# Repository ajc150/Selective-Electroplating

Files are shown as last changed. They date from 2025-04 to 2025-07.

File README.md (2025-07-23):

# Selective-Electroplating
Welcome to the Selective Electroplating GitHub!

This repository serves as a comprehensive introduction to CNC-based selective electroplating. Whether you're a student, researcher, or hobbyist, this guide provides everything you need to get started—from foundational electrochemical concepts to a full walkthrough of materials, setup, calibration, and image plating.

Here, you'll find:
* Step-by-step instructions for building and operating a selective electroplating system
* Supplementary code, G-code scripts, and CAD files for hardware fabrication
* Practical guidance on electrolyte preparation, process tuning, and image-based deposition

Use this page as a launchpad to explore the fundamentals of electroplating, then take it further—modify the system, test new metals, or optimize for finer detail. The project is built to be iterative and open-ended. Let the plating begin!
## Fundamentals
### Electroplating
Let's start with the basics - what even is electroplating?

Electroplating is an electrochemical process used to coat a conductive surface with a thin layer of metal. It works by running an electric current through a solution (called an electrolyte) that contains dissolved metal ions. The setup typically involves two electrodes:

* Anode — the donor metal that provides ions for plating
* Cathode — the object you want to coat (the workpiece)

Both electrodes are submerged in the electrolyte bath, and a DC power supply drives current through the system. The anode is connected to the positive terminal, and the cathode to the negative terminal. As current flows, metal atoms from the anode oxidize into positively charged ions and dissolve into the solution. These ions then migrate toward the negatively charged cathode, where they gain electrons (are reduced) and deposit as solid metal, bonding to the surface.
<p align="center">
  Description
</p>
The result? A controllable metal coating just microns thick—perfect for corrosion resistance, improved conductivity, or even aesthetics.

Common plating metals include nickel, copper, and zinc, while the items being plated are often steel, copper, or other conductive metals. The type of metal, bath composition, current, and plating time all play a role in determining the final coating quality.
### Masking
While tank plating is great for full-coverage applications, achieving selective or gradient control is a major limitation

To try and limit plating to specific areas, masks—physical barriers like tapes, waxes, or stencil-like coatings that block the electrolyte from reaching certain parts of the surface—are commonly used. While this can technically work, it comes with significant drawbacks:

* **Time-Intensive** — Designing, fabricating, and applying masks for complex parts takes time, especially if high precision is needed. Additionally, custom masks are not reusable in many cases.
* **Lack of Flexibility** — Once a mask is applied, you're locked into a binary outcome: plated vs. not plated. There’s no built-in way to vary how much metal gets deposited across a surface.
* **Messy Removal** — Mask removal after plating can be delicate and often introduces post-processing steps that add labor and cost.

If you're aiming for detailed patterns, gradual brightness variations, or image-quality precision, tank plating just doesn’t give you the level of spatial and temporal control required. Even advanced masking techniques can’t achieve what a dynamically controlled system can.
### CNC Basics
CNC stands for Computer Numerical Control—a method of automating tools using pre-programmed sequences of commands. Instead of manually operating a drill or mill, CNC machines follow G-code instructions to move a tool with precision across one or more axes. This allows for repeatable, high-resolution, and complex motion control, which is why CNCing is a staple in modern manufacturing.

In traditional CNC machining, tools like mills, routers, or lasers are used to remove material from a workpiece. But in this project, we flip the idea—using a CNC router to deposit material instead, in the form of metal ions through electroplating.
### Why use a CNC?
This setup lets us turn electroplating into a digital fabrication process. By controlling exactly when and where the plating occurs, we can:
* Create image-based metal patterns
* Plate complex shapes without masking
* Vary plating thickness across the surface
* Achieve high reproducibility across multiple runs

It also opens the door to applications in electronics (like programmable PCB masking), metal 3D printing, and metal-based art—anywhere spatial control over metal deposition matters.
## Materials
### Electroplating Components
* Electrolyte Bath Container (shallow plastic dish)
  * Holds the plating solution and the cathode (the surface to be plated). Needs to be chemically resistant.
* Electrolyte Solution
  * Nickel Sulfate (or Copper Sulfate/Zinc Sulfate) – Source of metal ions (**optional**)
  * Boric Acid (buffer) – Stabilizes pH during nickel plating
  * Sodium Chloride (table salt) – Improves conductivity (**optional** depending on solution)
  * Distilled Water – Solvent base for the electrolyte
  * 5% Household vinegar - solvent acid for the electrolyte (**optional**, only use if not using sulfate)
* Cathode (Object to be Plated)
  * Typically a copper PCB, steel plate, nickel plate, or other conductive surface you want to electroplate.
  * Note that copper cannot coat steel well, and the steel must be plated with nickel first.
* Anode (Donor Metal)
  * Nickel strip, copper strip, or zinc strip depending on plating metal
  * Positioned inside the nozzle or funnel to release ions when current flows.
### CNC Machine and Accesories
* CNC Router
  * Used to control the X, Y, and Z motion of the plating nozzle with high precision.
  * Acts as the programmable motion platform to trace out plating paths.
  * This projct uses a standard benchtop 3018 CNC router. Others may be used, but the smaller model is recommended due to price and modularity.
* G-code Sender Software
  * Software to send motion instructions (G-code) to the CNC in real-time.
  * Platform used in this project - Candle. Other personal favorites are equally as viable.
* Plastic Funnel or Nozzle Tip (3D printed)
  * Mounted to the CNC spindle holder; serves as the outlet for controlled electrolyte flow.
  * Two files attached, a [1 mm nozzle](/Funnel1mmnozzle.stl) and a [2 mm nozzle](/Funnel2mmnozzle.stl). Can print using PLA.
  * This project printed this file using an Ultimaker S3. If using another 3D printer, may need to adjust file tolerances.
* Clamp or Mount Adapter for Nozzle
  * Attaches the funnel/nozzle to the Z-axis tool holder of the CNC router.
  * One file attached, an [adapter for the benchtop 3018 CNC](/FunneltoCNCAdapter.stl). If using another CNC router, may need to create a custom design. Can print using PLA.
* Benchtop DC Power Supply
  * Provides controlled current (typically 4-6V, 1–20 mA) between the anode and cathode during plating. May need voltages of up to 20V depending on nozzle size and bath conductivity.
* Alligator Clips / Banana Plug Wires
  * For connecting the power supply to the anode and cathode. Ensure corrosion-resistant contacts.
### Cathode Setup
* Cleaning supplies
  * Hydrocloric/Muratic Acid - For cleaning and removing corrosion before plating.
  * Dish Soap - For degreasing metal before plating.
* Polishing Supplies (**optional**, depends on metal being plated or condition of metal)
  * Sandpaper (600, 800, 1000, 2000 grit) - used to grind metal down before plating to remove inconsistencies
  * Polishing kit - a jewelery polishing kit or drill kit can be used, ensures consistent surface before plating. Can also be used after plating to make an image shine.
### Miscellaneous and Safety
* Nitrile Gloves and Safety Glasses
  * Required for chemical safety when handling electrolyte and acids.
* pH Strips (**optional**)
  * Used to monitor the acidity of the solution. Only needed for solution troubleshooting
* Paper Towels / Wipes / Brushes
  * For cleaning surfaces before and after plating.
  * When cleaning after plating, use a microfiber cloth, KimWipe, or equivalent to avoid damaging plating while it is setting.
## Setup
### Electolyte Solution Setup
Store-bought electroplating solutions can be bought, however, they are often expensive and limit ingredient adjustability. It is recommended but not nessesary to make a homemade solution. There are two main ways to prepare your electrolyte solution, depending on your resources and desired metal. Both work well for CNC-based selective plating, but each has trade-offs in convenience, purity, and control. Note that this setup only covers the creation of a nickel solution, and for other plating metals (such as copper or zinc) different ratios and chemicals will be used. Feel free to look those recipes up, any solution can be used in this setup!
#### Option 1: Sulfate-based Electrolyte
This option is the quickest, and involves mixing dry powders into distilled water. Gather the following ingredients at the specified ratios:
* Nickel Sulfate Hexahydrate (NiSO₄·6H₂O) – 300 g/L (main source of ions)
* Boric Acid (H₃BO₃) – 40 g/L (pH buffer)
* Sodium Chloride (Table Salt) – 3 g/L (improve conductivity)
Mix with distilled water until fully disolved. Note that this will take a long time. An optional method to speed up the disolving process is to heat up slightly using a hot plate (microwave and stovetop can also work on low) to 50° Celsius. Final solution should be a medium green color.
#### Option 2: Vinegar-based Electrolyte
If you don’t have access to sulfate salts, you can make a functional electrolyte by charging vinegar (acetic acid) with the desired metal. This method is still highly effective, and majority of the testing of this project was done using this solution recipe. Gather the following ingredients:
* Vinegar (5%-30% acetic acid)
* 2 Nickel strips
* Boric Acid - 40 g/L
* Distilled water (if using 5%< acetic acid)
* Sodium chloride (Table Salt) - 3 g/L

Procedure:
1. Dilute vinegar to 5% in cointainer of chioce, add Sodium Chloride
2. Place strips of donor metal on edges of the container, so that most of the strip is submerged. Face the strips towards each other, ensuring at least 1 inch of space between them. Attach one strip to the positive terminal of the power supply and one strip to the negative terminal.
3. Set power supply to no more than 5 volts. This maximum value is flexible depending on bath and electrode size. Ensure that when plating no anode debris detatches without dissolving and deposits at the bottom of the container. If this does occur, lower the voltage.
4. Let it charge for 1-8 hours. This value depends on the bath and electrode size. The solution will be completed once it is a distict semi-opaque green color. It is better to make the solution over-dense than under-dense with ions.
5. Remove from power supply. Add 40 g/L of boric acid, stir until dissolved
<p align="center">
  Description
</p>
*Note that this image was an early test. Try to raise the liquid line to have a greater surface area of nickel submerged in the bath.

### CNC Setup
Once your plating solution is prepared, the next step is setting up the hardware—modifying your CNC 3018 to operate as a precision-controlled electroplating tool. This involves installing a custom nozzle, positioning the plating surface, wiring the electrodes, and preparing the system to accept G-code instructions.
#### Plating Nozzle
Download and print the provided STL files ([FunneltoCNCAdapter](/FunneltoCNCAdapter.stl) along with [Funnel1mmnozzle](/Funnel1mmnozzle.stl) or [Funnel2mmnozzle](/Funnel2mmnozzle.stl)) using PLA or any other chemically resistant material. Insert the nickel strip (anode) into the nozzle so it is suspended in the plastic without touching the bottom of the nozzle. There needs to be a minimum of ~0.5 inch gap between the nozzle hole and the anode. Achieve this by bending the nickel strip with pliers so that it is slightly wider than the opening, then pushing it firmly and carefully halfway into the funnel.
<p align="center">
  Description
</p>
Remove all milling tools from the CNC so that the attachment ring is hollow. Slide the adapter into the now empty slot and tighten the attachment screw. Ensure that the flat part of the adapter is parallel to the CNC machine. The nozzle is a tight friction fit with the adapter. Push the nozzle into the adapter firmly and ensure it is properly secured.

#### Workpiece and Wiring Setup
Before any plating begins, the surface of your cathode (the object you want to plate) must be clean, oil-free, and oxide-free. Contaminants like grease, fingerprints, or surface oxidation can severely hinder plating adhesion, causing patchy or failed results. Follow this cleaning process for reliable surface activation:

Optional: Sanding and Polishing
If your cathode surface is rough, oxidized, or scratched, you can improve both appearance and plating consistency with light surface finishing. 
* Use fine-grit sandpaper (e.g., 600–1000 grit) to remove heavy oxidation or scratches.
* For a mirror finish, follow up with metal polish and a soft cloth or polishing wheel.
* Sand in consistent strokes to avoid uneven plating patterns.
* Rinse the part with water and wipe clean before proceeding to degreasing.
A smoother surface results in a more even, reflective plating layer, and also makes it easier to see how well the plating is progressing during experiments.

Start cleaning by removing oils, dust, and general grime:
* Use warm water and dish soap (like Dawn) in a small container.
* Scrub the cathode thoroughly using a scratch-free scrubbing tool.
* Rinse well with distilled or tap water and dry with a lint-free cloth or paper towel.

To strip away surface oxides and lightly activate the metal for plating:
* Briefly immerse the cleaned cathode in a small container of hydrochloric acid for 30 seconds to 2 minutes depending on the metal.
* Use plastic tweezers or gloves—never touch the clean surface with bare hands after acid activation. Do not use metal pliers, they will corrode.
* Once done, rinse immediately and thoroughly with distilled water.
* Optionally, dry using compressed air or dab with a lint-free wipe.

**IMPORTANT** - Always wear gloves, goggles, and work in a well-ventilated area when handling hydrochloric acid. Never mix with other chemicals, especially bleach or zinc.

Plate immediately after cleaning, as oxidation can reform. Ensure all chemicals are closed and stored in a cabinet far away so that the metal does not re-oxidize.

With a clean surface, place the metal workpiece flat in the bottom of a shallow container filled with your prepared solution. Ensure it is completely horizontal and level to avoid uneven plating. The container should sit directly under the CNC toolhead, centered in the XY plane.
<p align="center">
  Description
</p>
Electroplating requires a closed electrical circuit:

* Anode (nickel strip inside nozzle) → Connect to the positive (+) terminal of your benchtop DC power supply
* Cathode (metal object at bottom of bath) → Connect to the negative (–) terminal
Use alligator clips or banana plug leads with corrosion-resistant contact points. Keep wires tidy and away from CNC motion paths

Make sure that when the z axis is in the "plating" position, the solution fully submerges the nickel anode.

## Code Setup and Calibration
Once the physical setup is complete, it’s time to generate the G-code that will control your CNC’s motion during plating. This section walks you through connecting your CNC machine, editing the G-code generator script, and calibrating your parameters for the best results.
### Calibration
The provided Python script, [gammaTesterGCODEgenerator.py](/gammaTesterGCODEgenerator.py), will generate a set of G-code instructions to draw one or more gradient lines based on brightness values. Open gammaTesterGCODEgenerator.py in your preferred code editor. Carefully read the embedded comments to understand how to set the number of lines, adjust line spacing, define resolution and pixel-to-mm scale, and control dwell time based on brightness values.

Before you start fine-tuning gradients, you need to determine the maximum effective dwell time—the longest time the nozzle should remain stationary at a single point before additional time stops affecting plating color.

How to Test:
1. In the Python script, set a large value for step_distance (e.g., 3 mm) and a medium-large value for max_dwell_time (e.g., 20-40 seconds)
2. Generate and run the G-code.
3. Observe the line of dots created—look for the first dot that appears fully and consistently plated.
4. That dwell time is now your experimental max dwell time (write it down).

Once you’ve established your max dwell time, you can now experiment with different values of gamma to control how steep or shallow the brightness-to-dwell relationship is.

How to Test:
1. Keep your calibrated max dwell time
2. Generate 20 or more lines, each with a different gamma value (e.g., 1 to 6.0, 0.25 increments) and small step_distance (e.g., 1 mm step_distance for 2 mm nozzle)
3. Run the G-code and observe the differences

In general, low gamma values will show more uniform plating, and high gamma values will create sharper contrasts. An example of this function call can be found as a comment.
### Interpreting Results
The series of gradient lines you just generated is more than just a test-it’s a personalized plating reference guide tailored to your machine, solution, and conditions.

Each line, defined by a specific gamma value, shows how the plating appears across the same brightness range (from 0 to 255). You’ll notice some lines have a smooth gradient, while others transition more sharply. This helps you determine how brightness maps to dwell time—and in turn, to plating thickness.

Choosing the Right Gamma for Your Project:
* Darker images (low brightness) generally benefit from lower gamma values (e.g., 2.0-3.5), as they stretch out low brightness levels and emphasize subtle tones.
* Brighter images benefit from higher gamma values (e.g., 3.5-5.0), which compress low brightness and stretch out highlights for greater control.
<p align="center">
  Description
</p>
A sample output from the gamma calibration test is shown below. This gives you a visual idea of how line spacing, dwell time, and gamma interact to produce various plating intensities. The dots at the bottom test for max dwell time, and the lines at the top test gamma values.

### Sending GCODE to the CNC
Once you’ve generated a final G-code file using the desired gamma and parameters, follow these steps to run your plating job:
1. Open your G-code sender software
2. Connect to your CNC via USB and confirm the COM port.
3. Use the "Open File" button to load your .gcode file.
4. Manually jog the machine to the x and y starting position (the bottom-left most part of the image to be plated) and home the x and y positions.
5. Set your Z-height - if the plate is warped, find the "tallest" region of the object being plated, then raise the nozzle ~0.1 mm above it. This can be done by eye, however it is recommended to use aluminum foil for more consistent results. Submerge the foil between the nozzle and the object being plated, then move the z axis down so that the foil is secured. Then, carefully without ripping the foil, incrementally increase the z axis height by 0.1 mm until the foil is free to move. Home the z axis at this point.
6. Double-check all wiring and power supply settings (as described earlier).
7. Hit "Send" and monitor the plating process as the CNC runs through the motion path.

**IMPORTANT** - Watch the first few movements closely. Pause or abort the job if there's dripping, shorts, or off-target movement.

### Image to GCODE Conversion
Now that you've calibrated your setup and tested gamma values, you're ready to plate real images using the [endpointGammaGCODEgenerator.py](/endpointGammaGCODEgenerator.py) script. This script converts a greyscale image into a path of CNC movements, where darker areas receive more plating and lighter areas receive less—with control over contrast using gamma and endpoint values.

This script includes two main functions:
1. generate_preview() – Generates a visual preview of how the brightness map will convert into CNC dwell times. Use this to check before plating.
2. image_to_GCODE() – Converts the image into a .gcode file with CNC instructions for selective electroplating.

The script includes embedded comments—read through them carefully to understand how to set image resolution and scale, define your max dwell time, control spacing and movement and adjust gamma and endpoints

Download or open the endpointGammaGCODEgenerator.py script. Place the image you'd like to plate (in .png or .jpg format) in the same folder as the script. Rename the image if needed and update the filename reference in the script accordingly.

Unlike the previous script which used a full brightness range (0–255), this one lets you focus the gradient within a specific brightness window, ideal for better contrast and plating accuracy.

How to Determine Endpoints:
1. Use the test piece you plated earlier with the gammaTesterGCODEgenerator.py script as your guide.
2. Find the leftmost region where plating is fully saturated (maximum darkness).
3. Find the rightmost region where minimum plating occurred (near-bare surface).
4. Note the corresponding brightness values (or just estimate by eye).
5. Set these as your inner range, and expand the window slightly by about ±0.2 to get your gamma endpoints.

For example:
* Fully plated = brightness 0.7
* Bare = brightness 0.4

You could set your endpoints as:
* min_brightness = 0.2
* max_brightness = 0.9

These endpoint values help stretch the plating gradient to give more visible variance in your final result.

Note - Always use the preview_image() function first to visually check how your image will map to dwell time. This gives you a good sense of where you'll get strong plating and where light areas will remain subtle. You can adjust parameters according to this preview or if unhappy with plating results.

Read the "Sending GCODE to the CNC" section above for instruction on how to send the generated GCODE to the machine
### Post-Processing: Cleaning, Sealing, and Finishing
Once plating is complete, there are a few important steps to preserve the finish, remove residue, and optionally enhance the appearance of your part. Skipping post-processing can lead to oxidation, contamination, or a dull, uneven finish.

As soon as the plating is finished:
* Remove the part from the bath using tweezers or gloved hands.
* Rinse thoroughly with distilled water to wash off any remaining electrolyte.
* If needed, follow up with an alcohol or isopropyl rinse to promote fast drying.
* Dry completely using compressed air, a lint-free cloth, or low-heat drying (e.g., hair dryer).
Avoid letting electrolyte dry on the part—it can leave behind salt residue and tarnish the finish.

Optional: Buffing and Polishing

If you're after a reflective or smooth surface:
* Lightly buff the part using a soft cloth or rotary buffer.
* A small amount of metal polish can enhance shine, but avoid over-polishing thin coatings.
* Only polish once the coating is confirmed to be well-adhered and dry.

Note - it is not recommended to polish the surface of most images, as the buffing can remove the less plated regions. Reserve polishing for "binary" black and white/plated and unplated images. Experiment at your own risk.

Optional: Protective Coating

To prevent oxidation or environmental damage
* Apply a clear acrylic spray, lacquer, or wax-based coating if long-term exposure is expected.

## Results
After all the setup, calibration, and G-code generation, this section is dedicated to showing what successful selective electroplating can look like using this CNC-driven approach.








## Questions?
email me! At ajc150@duke.edu, I'll be sure to respond quickly!

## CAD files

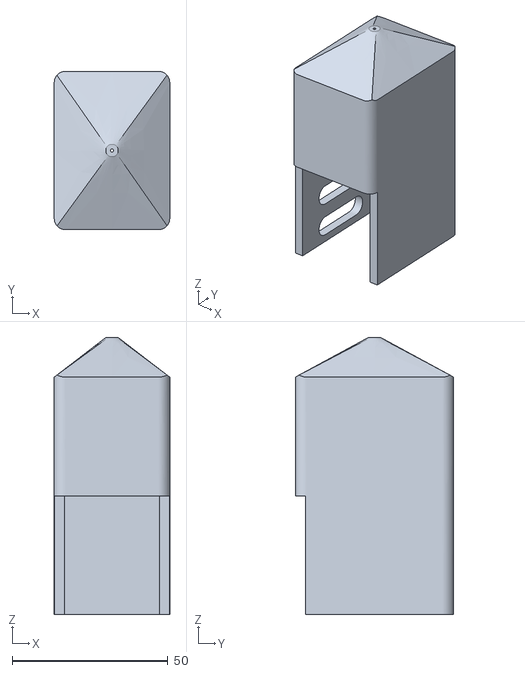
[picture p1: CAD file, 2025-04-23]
Funnel1mmnozzle.stl
37.1 x 50.8 x 88.9

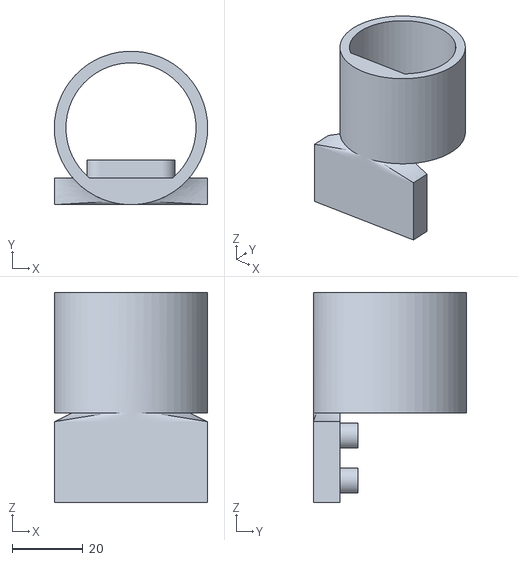
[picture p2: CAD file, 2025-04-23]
FunneltoCNCAdapter.stl
43.4 x 43.4 x 59.4

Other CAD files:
Funnel2mmnozzle.stl

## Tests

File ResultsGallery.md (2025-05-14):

# Results Gallery

<table>
  <tr>
    <td></td>
    <td></td>
    <td></td>
  </tr>
  <tr>
    <td></td>
    <td></td>
    <td></td>
  </tr>
</table>

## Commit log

2025-04-25 Rename Funnel 1 mm nozzle.stl to Funnel1mmnozzle.stl
    [Funnel1mmnozzle.stl]
2025-04-25 Rename Funnel 2 mm nozzle.stl to Funnel2mmnozzle.stl
    [Funnel2mmnozzle.stl]
2025-04-25 Rename Funnel to CNC Adapter.stl to FunneltoCNCAdapter.stl
    [FunneltoCNCAdapter.stl]
